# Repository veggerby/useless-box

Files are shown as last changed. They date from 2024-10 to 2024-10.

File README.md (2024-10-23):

# Useless Box

The non-attributed and non-adapted work in this repository is licensed under the [MIT LIcense](https://opensource.org/license/mit).

All files in [adjusted folder](./resources/adjusted/) are apapted work from [@balassy](https://www.thingiverse.com/thing:3856965) 3D models on Thingiverse and are licensed under [CC BY-NC-SA 4.0](https://creativecommons.org/licenses/by-nc-sa/4.0/).

## Attribution

This concept and 3D model for the enclosure, mechanical and eletronic design is based on [useless-box](https://github.com/balassy/useless-box/) and [Smart Useless Box with ESP8266 and Gesture Sensor](https://www.thingiverse.com/thing:3856965).

All source code has been created from scratch.

3D Sketches available on [Thingiverse](https://www.thingiverse.com/thing:3856965), with [local copy](./resources/Smart%20Useless%20Box%20with%20ESP8266%20and%20Gesture%20Sensor%20-%203856965.zip) and extracted [here](./resources/originals/3d-print/). These files are licensed under [CC BY-NC-SA 4.0](https://creativecommons.org/licenses/by-nc-sa/4.0/) attributed to [György Balássy](https://www.thingiverse.com/balassy/designs).

The included [Fritzing schematics](./resources/originals/Useless-Box-Shield-v1.fzz) are directly from the [GitHub repository](https://github.com/balassy/useless-box/blob/master/wiring/Useless-Box-Shield-v1.fzz) and licesed under [MIT LIcense](https://opensource.org/license/mit) attributed to György Balássy ([@balassy](https://github.com/balassy)).

## Firnware

Using [ESP32-C3 Super Mini](https://ardustore.dk/produkt/esp32-c3-super-mini-wifi-4mb-ble5-udviklingsboard)

[Datasheet](./resources/ESP32C3%20Datasheet.PDF) from [ardustore.dk](https://ardustore.dk/error/ESP32C3%20Datasheet.PDF)

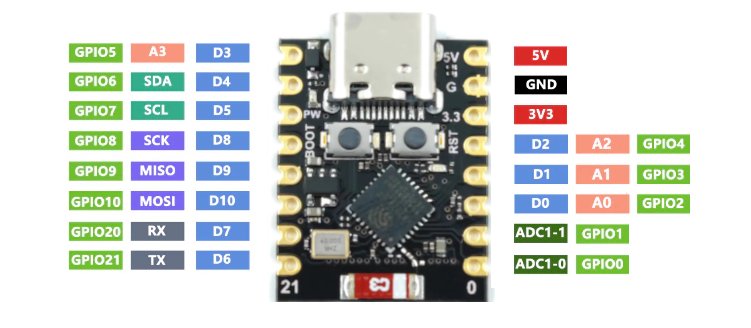
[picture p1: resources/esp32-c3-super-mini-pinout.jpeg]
ESP32-C3 Super Mini
Pinout  from [arduinio.cc](https://forum.arduino.cc/t/esp32-c3-supermini-pinout/1189850)

See [ESP32-C3 Super Mini](https://www.sudo.is/docs/esphome/boards/esp32c3supermini/) on sudo.is.

[Generic ESP32-C3 firmware](https://micropython.org/download/ESP32_GENERIC_C3/).

Included parts for the Fritzing schematics:

* [ESP32-C3 Super Mini](./resources/esp32-c3-super-mini-tht.fzpz) (from [Fritzing Forum](https://forum.fritzing.org/t/need-esp32-c3-super-mini-board-model/20561) - [direct link](https://forum.fritzing.org/uploads/short-url/oE2T2GupmkPLZawp5EHPnzf3vFM.fzpz))
* [SG90](./resources/Tower%20Pro%20SG90%20servo.fzpz) which is compatible with the MG90S used in this design (from [SolderedElectronics/e-radionica.com-Fritzing-Library-parts-](https://github.com/SolderedElectronics/e-radionica.com-Fritzing-Library-parts-/tree/master) GitHub repo - [direct link](https://github.com/SolderedElectronics/e-radionica.com-Fritzing-Library-parts-/blob/master/Tower%20Pro%20SG90%20servo.fzpz))
* [APDS-9960](./resources/12787_sfe_apds_9960_rgb_and_gesture_sensor.fzpz) (from [sparkfun/Fritzing_Parts](https://github.com/sparkfun/Fritzing_Parts/tree/main/products) GitHub repo - [direct link](https://github.com/sparkfun/Fritzing_Parts/blob/main/products/12787_sfe_apds_9960_rgb_and_gesture_sensor.fzpz))
* [2 Pin Toggle Switch](./resources/Toggle%20Switch%20spst.fzpz) (from [Fritzing Forum](https://forum.fritzing.org/t/special-type-of-spst-part/6125) - [direct link](https://forum.fritzing.org/uploads/default/original/2X/1/1c25cedde9474dec93b1165daffaadfd2b2697d7.fzpz))

### Flash

```sh
brew install esptool
```

or

```sh
pip install esptool
```

Flash ESP32:

```sh
esptool.py --chip esp32c3 --port /dev/cu.usbmodem1452201 erase_flash
esptool.py --chip esp32c3 --port /dev/cu.usbmodem1452201 --baud 460800 write_flash -z 0x0 ./firmware/ESP32_GENERIC_C3-20240602-v1.23.0.bin
```

## Components

* 1 mini breadboard
* 1 x [ESP32-C3 Super Mini](https://ardustore.dk/produkt/esp32-c3-super-mini-wifi-4mb-ble5-udviklingsboard)
* 2 x [MG90S](https://www.amazon.de/dp/B095YVLLFQ) this is compatible with the original SG90, but is more robust (metal gears) and quieter
* 1 x [APDS-9960](https://www.amazon.de/dp/B01HV41XJO) ([library](https://github.com/liske/python-apds9960))
* 1 x [2 Pin Mini On/Off Toggle Switch](https://www.amazon.de/dp/B07MS8X99G)
* 1 x 1 kΩ resistor (color code Brown-Black-Red-Gold for reference)
* Various M2 and M3 screws, nuts and washers

## 3DPrinted Box

The original files from [balassy](https://www.thingiverse.com/thing:3856965) has been adjusted to accomodate the slightly larger controller on a mini breadboard (with extended). Additionally the micro USB port has been adjusted size and position for the USB-C port on the used ESP-C3 Super Mini.

Additionally mounts have been added to the box bottom, to allow for better mounting of the servo for the lid on the box-base, using 2 M2 screws.

## Useless-Box Behavior Overview

This version of the useless-box has a controller which manages the behavior/response of the useless-box to stimuli/input. The implemented behaviors are:

### 1. Initial Setup and Idle State

* **When the program starts**, the controller initializes the box components, including the switch arm, lid arm, proximity sensor, toggle switch, and LED.
* The system enters the **IDLE** state initially, waiting for any user interaction (such as the proximity of a hand or the toggle switch being activated).

### 2. Monitoring and Responding to Proximity and Switch State

* The `update()` method continuously monitors the proximity sensor and the state of the toggle switch.
* The box reacts based on proximity levels (`VERY_CLOSE`, `CLOSE`, or `FAR`) and the toggle switch state (`On` or `Off`). Here's how each condition is handled:

### 3. Switch State Changes

* **If the toggle switch is turned on** (`current_switch` becomes `True`):
  * The system enters the `SWITCH_OFF` state.
  * The LED is turned **on** to signal the activation.
  * A **random delay** (shorter or longer, with more frequent short delays) is introduced before switching off the toggle.
  * The `_handle_switch_toggle()` method is called, which:
    * Opens the lid.
    * Attempts to switch off the toggle. If it fails, it retries up to three times.
    * Retracts the switch arm and closes the lid afterward.
  * The LED is turned **off** again, and the state resets to **IDLE**.

### 4. Proximity: Very Close Interaction

* **If a hand is detected very close** (`ProximityState.VERY_CLOSE`) and the box is in the `IDLE` state:
  * There is a **5% chance** of the box playing a **peek-a-boo** animation:
    * The lid opens slightly and then closes.
  * There is also a **20% chance** of the box threatening to turn off the toggle:
    * The switch arm moves to a halfway position as if threatening, then retracts.
  * If neither occurs, the box simply acknowledges the hand's presence but does nothing more.

* **If the lid is already open** when the hand is very close:
  * The box ensures the lid stays closed to prevent any tampering.
  * Occasionally, it might perform a **peek-a-boo** with a **1% probability**.
  * The LED blinks slowly when the hand is very close.

### 5. Proximity: Close Interaction

* **If a hand is detected close** (`ProximityState.CLOSE`) and the box is in the `IDLE` state:
  * There is a **30% chance** the box will perform a **fake-out**:
    * The lid opens slightly and quickly closes.
  * Otherwise, it enters the `TEASING` state and performs a teasing animation:
    * The lid opens to a random angle (50% to 100%), pauses, and then closes.

### 6. Proximity: Far Interaction

* **If the hand moves away** (`ProximityState.FAR`) and the box is not in the `IDLE` state:
  * The box returns to the **IDLE** state.
  * The LED is turned **off**.
  * The lid is closed if it is open, and the switch arm is retracted.

### 7. Inactivity Timeout

* The box monitors the duration since the last interaction. If the time exceeds the set `inactivity_timeout` (5 seconds in this case):
  * If the lid is open (`LID_OPEN` state), the box closes the lid and retracts the switch arm to its default position.

### 8. Panic Mode

* **If the user toggles the switch repeatedly** (three times within three seconds):
  * The box enters **panic mode**, where it:
    * Rapidly opens and closes the lid while blinking the LED for five cycles.
  * The state returns to **IDLE** after the panic mode completes.

### 9. LED Behavior Based on Proximity

* The LED behavior is tied to proximity:
  * **Very Close**: LED blinks slowly (on for half a second, off for half a second).
  * **Close**: LED blinks rapidly (on for 0.1 seconds, off for 0.1 seconds).
  * **Far**: LED remains off.

### Summary

* The `UselessBoxController` reacts dynamically based on the proximity of a hand and the toggle switch state. It performs quirky behaviors like teasing, fake-outs, peek-a-boo, threatening gestures, and panic mode to entertain and surprise users.
* The randomness introduced (through probabilities and delays) ensures that the box feels unpredictable and playful, making interactions more engaging.
* The box also incorporates safety measures, such as ensuring the lid stays closed when the hand is too close and resetting states after inactivity, providing a consistent user experience.

## Additional Works

* [Useless Box PRO with ESP8266 and Gesture Sensor](https://www.thingiverse.com/thing:5787968) remix from original

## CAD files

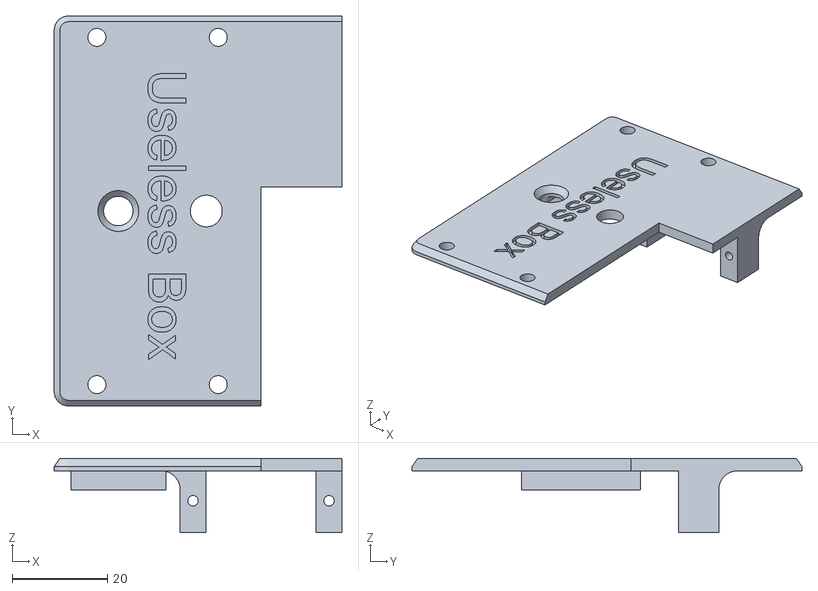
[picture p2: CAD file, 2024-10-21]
resources/adjusted/Fixed Lid.stl
60.5 x 82.0 x 15.6

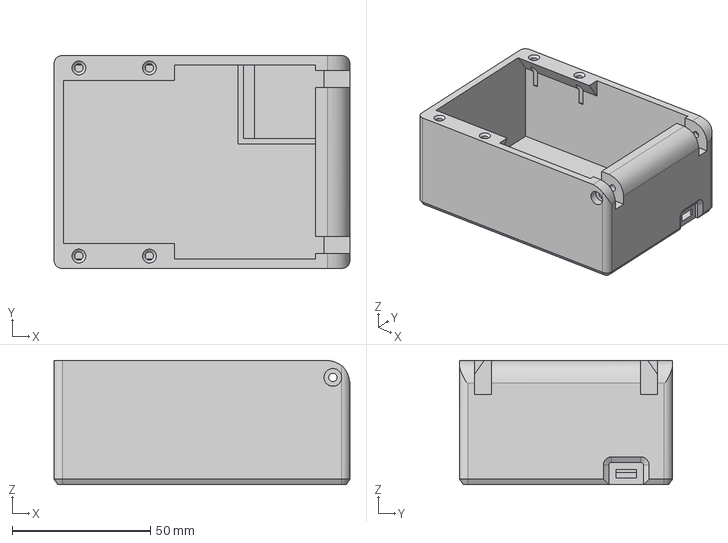
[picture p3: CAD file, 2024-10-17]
resources/originals/3d-print/files/Smart_Useless_Box_base_v1.step
107.0 x 77.0 x 45.0 mm

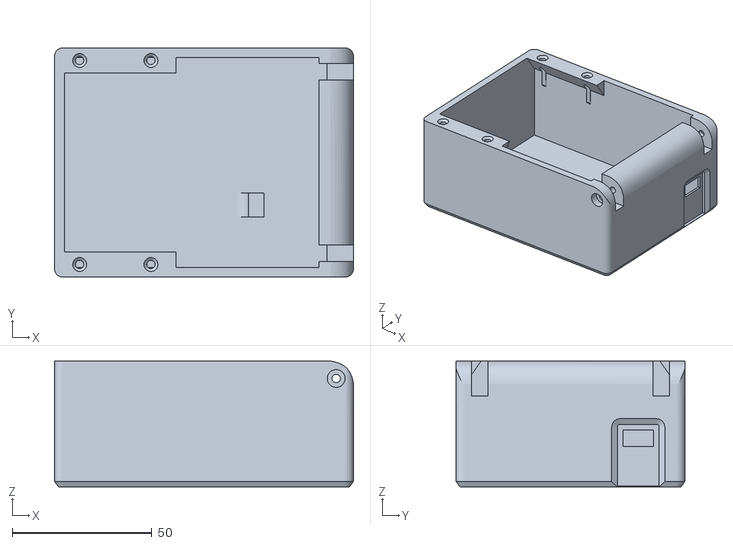
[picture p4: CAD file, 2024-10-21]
resources/adjusted/Box Base.stl
107.0 x 82.0 x 45.0

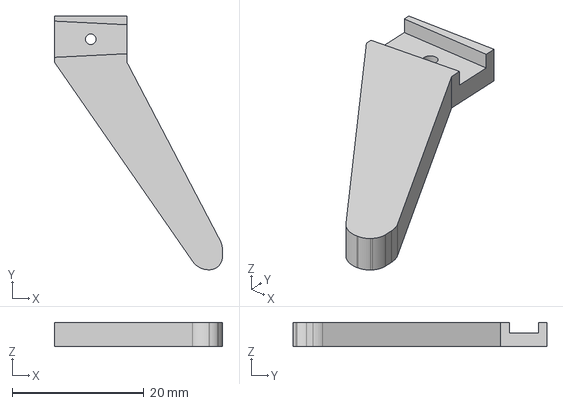
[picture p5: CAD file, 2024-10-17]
resources/originals/3d-print/files/Smart_Useless_Box_lid_arm_v1.step
25.5 x 38.5 x 3.70 mm

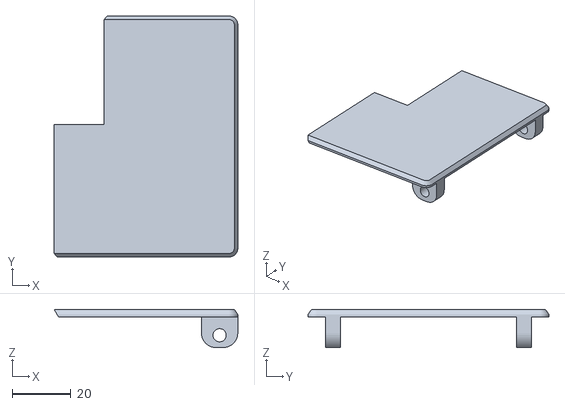
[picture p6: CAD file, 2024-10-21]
resources/adjusted/Moving Lid.stl
62.5 x 82.0 x 13.0

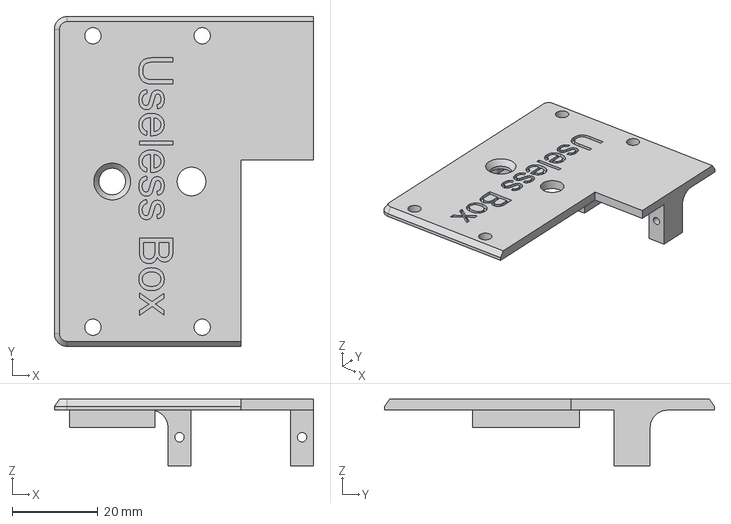
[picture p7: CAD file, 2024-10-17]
resources/originals/3d-print/files/Smart_Useless_Box_fixed_lid_v1.step
60.5 x 77.0 x 15.6 mm

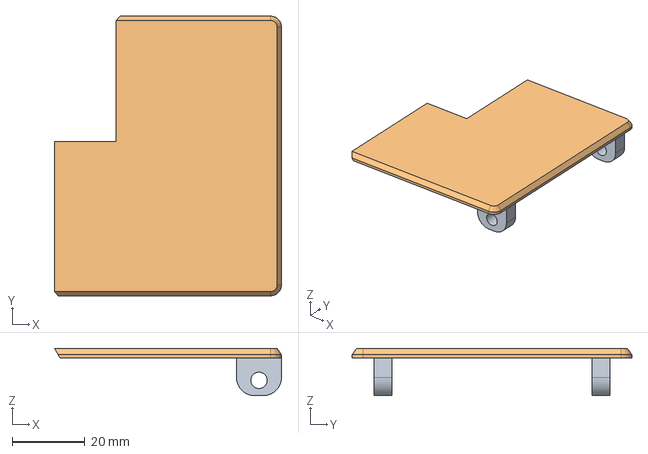
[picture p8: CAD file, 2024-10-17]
resources/originals/3d-print/files/Smart_Useless_Box_moving_lid_v1.step
62.5 x 77.0 x 13.0 mm

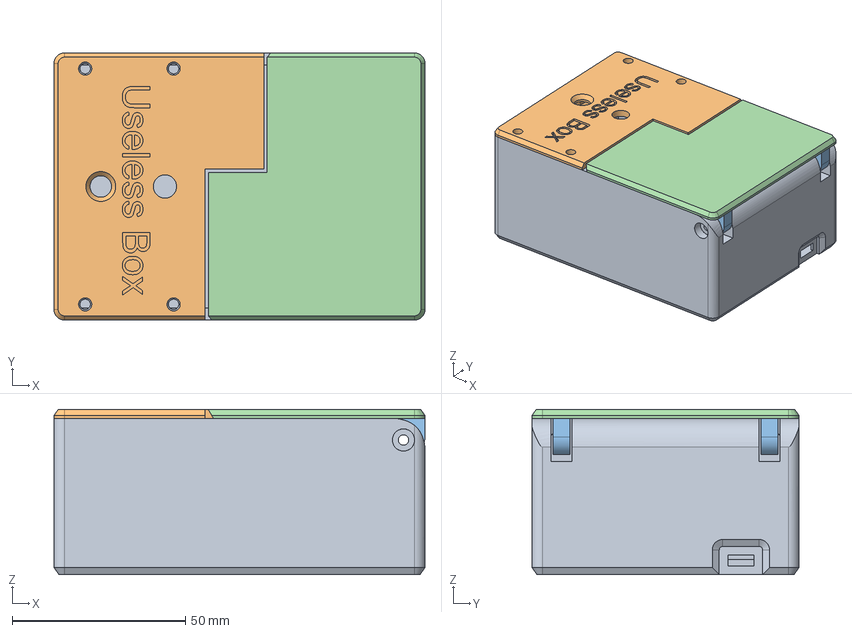
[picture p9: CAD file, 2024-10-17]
resources/originals/3d-print/files/Smart_Useless_Box_box_v1.step
107.0 x 77.0 x 47.6 mm
Box Base
Fixed Lid
Moving Lid

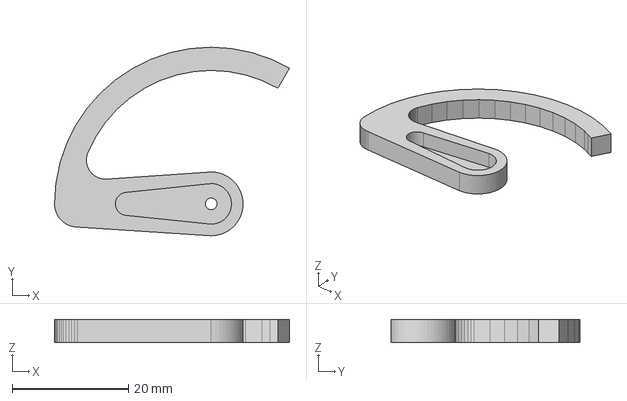
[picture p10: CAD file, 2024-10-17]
resources/originals/3d-print/files/Smart_Useless_box_switch_arm_v1.step
40.5 x 32.5 x 4.00 mm

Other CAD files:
resources/adjusted/Smart_Useless_Box_box_v2.f3d
resources/originals/3d-print/files/Smart_Useless_Box_base_v1.stl
resources/originals/3d-print/files/Smart_Useless_Box_box_v1.f3d
resources/originals/3d-print/files/Smart_Useless_Box_fixed_lid_v1.stl
resources/originals/3d-print/files/Smart_Useless_Box_lid_arm_v1.f3d
resources/originals/3d-print/files/Smart_Useless_Box_lid_arm_v1.stl
resources/originals/3d-print/files/Smart_Useless_Box_moving_lid_v1.stl
resources/originals/3d-print/files/Smart_Useless_box_switch_arm_v1.f3d
resources/originals/3d-print/files/Smart_Useless_box_switch_arm_v1.stl

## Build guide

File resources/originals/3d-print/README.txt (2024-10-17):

Smart Useless Box with ESP8266 and Gesture Sensor by balassy on Thingiverse: https://www.thingiverse.com/thing:3856965

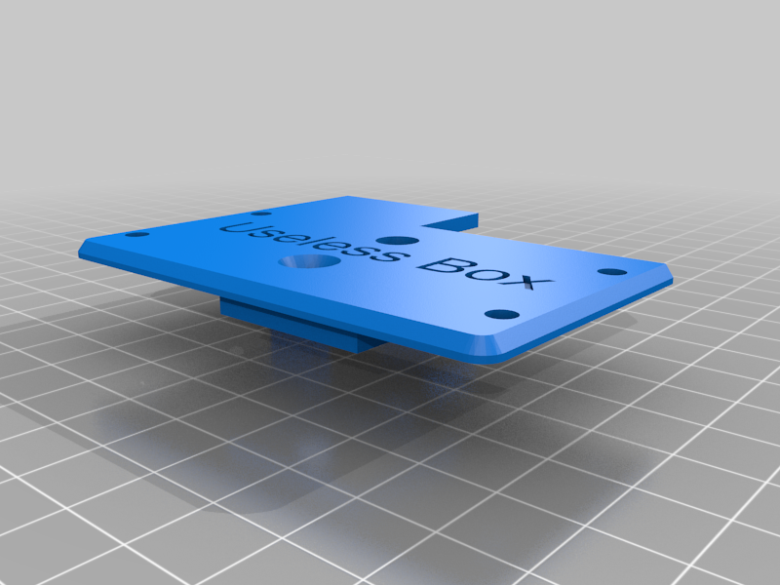
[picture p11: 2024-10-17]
resources/originals/3d-print/images/Smart_Useless_Box_fixed_lid_v1.png

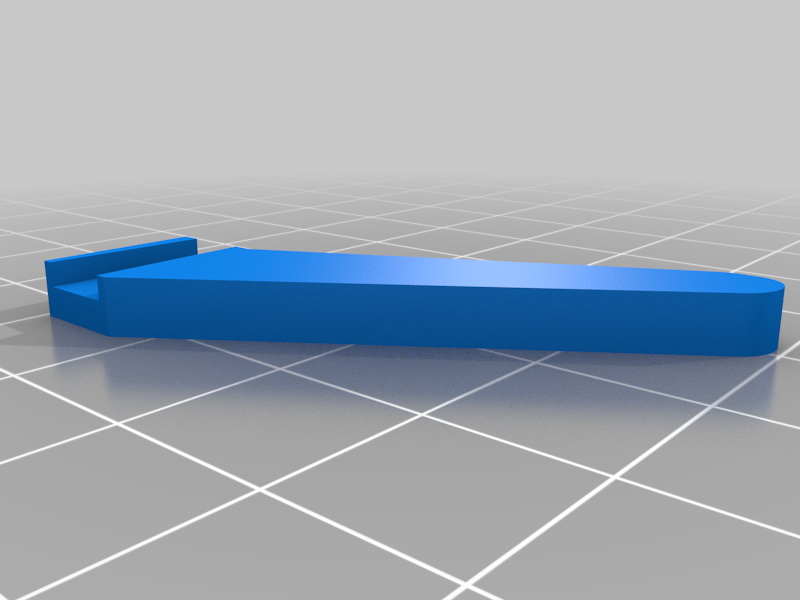
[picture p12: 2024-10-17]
resources/originals/3d-print/images/Smart_Useless_Box_lid_arm_v1.png

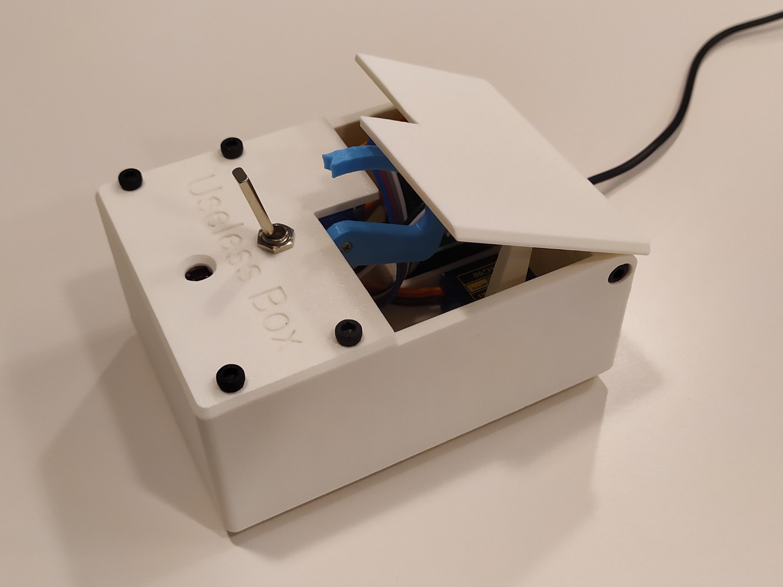
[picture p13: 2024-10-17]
resources/originals/3d-print/images/Smart_useless_box_1.jpg

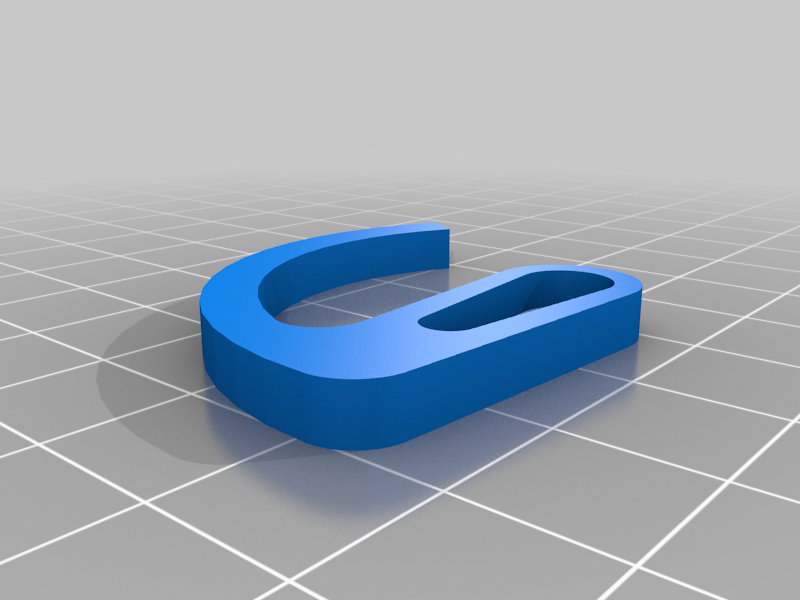
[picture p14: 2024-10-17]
resources/originals/3d-print/images/Smart_Useless_box_switch_arm_v1.png

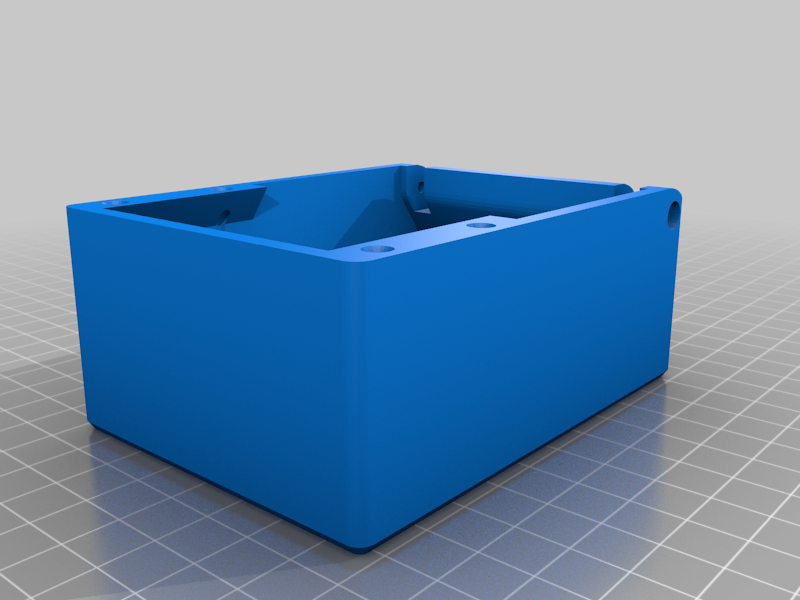
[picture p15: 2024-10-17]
resources/originals/3d-print/images/Smart_Useless_Box_base_v1.png

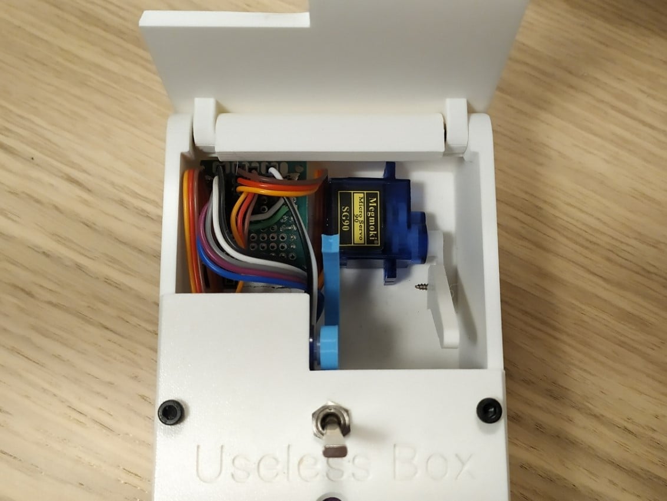
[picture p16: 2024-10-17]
resources/originals/3d-print/images/IMG_20210421_183354.jpg

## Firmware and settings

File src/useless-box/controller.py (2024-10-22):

import random
import time
from proximity import ProximityState
from led import LED
from useless_box import UselessBox

class UselessBoxController:
    PEEKABOO_PROBABILITY = 0.05  # Probability for peek-a-boo (5%)
    THREATEN_PROBABILITY = 0.2   # Probability for threatening movement (20%)
    PEEKABOO_RARE_PROBABILITY = 0.01  # Probability when hand is very close (1%)

    IDLE = 0
    LID_OPEN = 1
    TEASING = 2
    SWITCH_OFF = 3

    MAX_SWITCH_ON_TIME_SECS = 10

    def __init__(self, switch_pin, lid_pin, sda_pin, scl_pin, toggle_pin, led_pin, inactivity_timeout=5):
        """
        Initializes the UselessBoxController with the necessary components.
        :param switch_pin: GPIO pin connected to the switch arm servo.
        :param lid_pin: GPIO pin connected to the lid arm servo.
        :param sda_pin: GPIO pin used for the I2C data line (SDA).
        :param scl_pin: GPIO pin used for the I2C clock line (SCL).
        :param toggle_pin: GPIO pin connected to the toggle switch.
        :param led_pin: GPIO pin connected to the LED.
        :param inactivity_timeout: Time in seconds before the lid closes automatically if no interaction occurs.
        """
        self.box = UselessBox(switch_pin, lid_pin, sda_pin, scl_pin, toggle_pin)
        self.led = LED(led_pin)  # Initialize the onboard LED
        self.state = UselessBoxController.IDLE
        self.last_state = None
        self.last_proximity = None
        self.last_switch_state = None
        self.inactivity_timeout = inactivity_timeout  # Inactivity timeout in seconds
        self.last_interaction_time = time.time()  # Track the last time an interaction occurred
        self.switch_off_count = 0
        self.last_off_time = time.time()
        self.last_on_time = None

    def run(self):
        """
        Main method to run the interactive sequences based on user input.
        """
        while True:
            self.update()

    def update(self):
        """
        Updates the box's behavior based on the state of the toggle switch and proximity sensor.
        """
        current_switch = self.box.get_switch_state()
        proximity = self.box.get_proximity()

        # Output proximity state only if it has changed
        if proximity != self.last_proximity:
            print(f"Proximity state: {proximity}")

        # Output switch state only if it has changed
        if current_switch != self.last_switch_state:
            print(f"Switch state: {'On' if current_switch else 'Off'}")

            if current_switch:
                self.last_on_time = time.time()

        if self.state != self.last_state:
            print(f"State: {self.state}")

        self.last_state = self.state

        # Check for interactions and update the state
        if current_switch and not self.last_switch_state:
            self.state = UselessBoxController.SWITCH_OFF
            self.led.on()  # Turn on the LED when the switch is turned on
            self._random_delay()  # Introduce a random delay before switching off
            self._handle_switch_off()
            self._reset_inactivity_timer()

        elif proximity == ProximityState.VERY_CLOSE and self.state == UselessBoxController.IDLE:
            # Occasionally play peek-a-boo (5% chance)
            if random.random() < UselessBoxController.PEEKABOO_PROBABILITY:
                self.state = UselessBoxController.LID_OPEN
                self._handle_peekaboo()
                self._reset_inactivity_timer()
            # Occasionally move the switch arm to a threatening position (20% chance)
            elif random.random() < UselessBoxController.THREATEN_PROBABILITY:
                print("Threatening to switch off!")
                self._handle_threaten()
                self._reset_inactivity_timer()
            else:
                print("Hand detected very close, but not playing peek-a-boo or threatening this time.")

        elif proximity == ProximityState.CLOSE and self.state == UselessBoxController.IDLE:
            if random.random() < 0.3:  # 30% chance of doing a fake-out
                self._handle_fakeout()
            else:
                self.state = UselessBoxController.TEASING
                self._handle_tease()
            self._reset_inactivity_timer()

        elif proximity == ProximityState.FAR and self.state != UselessBoxController.IDLE:
            self.state = UselessBoxController.IDLE
            self.led.off()  # Turn off the LED when returning to idle
            self._handle_close_lid()
            self._reset_inactivity_timer()

        # If proximity is very close, ensure the lid stays closed and occasionally blink the LED
        elif proximity == ProximityState.VERY_CLOSE:
            if self.state != UselessBoxController.IDLE:
                print("Hand too close, keeping the lid closed.")
                self._handle_close_lid()
                self.led.off()
            # Occasionally do a peek-a-boo, even when proximity is very close, and blink the LED
            elif random.random() < UselessBoxController.PEEKABOO_RARE_PROBABILITY:
                self.led.toggle()  # Blink the LED occasionally
                self.state = UselessBoxController.LID_OPEN
                self._handle_peekaboo()
                self._reset_inactivity_timer()

        # If the switch is turned on for a long time, switch off automatically
        if current_switch and self.state == UselessBoxController.IDLE and self.last_on_time is not None and time.time() - self.last_on_time > self.MAX_SWITCH_ON_TIME_SECS:
            print("Switch has been on for a while. Turning it off automatically.")
            self._handle_switch_off()

        # Close the lid if it is open and there has been no interaction for the specified inactivity period
        if time.time() - self.last_interaction_time > self.inactivity_timeout:
            if self.state == UselessBoxController.LID_OPEN:
                print("No interaction detected for a while. Closing the lid.")
                self._handle_close_lid()

        self.update_led_based_on_proximity(proximity)  # Update LED pattern based on proximity

        self.last_switch_state = current_switch
        self.last_proximity = proximity
        time.sleep(0.2)  # Small delay for responsiveness

    def _random_delay(self):
        """
        Introduces a random delay before taking action after the switch is turned on.
        Short delays are more common, with longer delays being rarer.
        """
        random_value = random.uniform(0, 1)
        if random_value < 0.3:
            chosen_delay = 0.5
        elif random_value < 0.6:
            chosen_delay = 1.0
        elif random_value < 0.8:
            chosen_delay = 1.5
        elif random_value < 0.9:
            chosen_delay = 2.0
        elif random_value < 0.95:
            chosen_delay = 3.0
        else:
            chosen_delay = 5.0

        print(f"Introducing a delay of {chosen_delay} seconds.")
        time.sleep(chosen_delay)

    def update_led_based_on_proximity(self, proximity):
        if proximity == ProximityState.VERY_CLOSE:
            self.led.on() if time.time() % 1 < 0.5 else self.led.off()  # Blink slowly
        elif proximity == ProximityState.CLOSE:
            self.led.on() if time.time() % 0.2 < 0.1 else self.led.off()  # Blink quickly
        else:
            self.led.off()

    def _handle_switch_off(self):
        """
        Handles the switch toggle interaction.
        Ensures the switch is actually turned off by the arm.
        """
        current_time = time.time()
        if current_time - self.last_off_time < 3:
            self.switch_off_count += 1
        else:
            self.switch_off_count = 1
        self.last_off_time = current_time

        if self.switch_off_count >= 3:
            self._handle_panic_mode()
            self.switch_off_count = 0
            return

        print("Switch turned on, attempting to turn it off.")
        self.box.open_lid(100, 500)
        time.sleep(0.5)  # Small delay to give a visual effect of the lid opening

        # Attempt to turn off the switch
        for attempt in range(3):
            print(f"Attempt {attempt + 1} to switch off.")
            self.box.switch_arm.extend(100, 500)  # Move the switch arm fully to turn the switch off
            time.sleep(0.5)  # Hold position to ensure it engages
            self.box.switch_arm.retract(100, 500)  # Retract the switch arm after switching off

            # Recheck the switch state after attempting to turn it off
            if not self.box.get_switch_state():
                print("Switch successfully turned off.")
                break
            else:
                print("Switch still on, retrying...")

        self.box.close_lid(100, 500)  # Close the lid fully
        self.led.off()  # Turn off the LED after handling the toggle
        self.state = UselessBoxController.IDLE

    def _handle_peekaboo(self):
        """
        Handles the peek-a-boo interaction.
        """
        self.box.play_peekaboo()
        self.state = UselessBoxController.IDLE

    def _handle_tease(self):
        """
        Handles the teasing interaction with a random lid angle.
        """
        random_angle = random.randint(50, 100)  # Randomly choose an angle between 50% and 100%
        print(f"Teasing with lid opening to {random_angle}%")
        self.box.open_lid(random_angle, 500)
        time.sleep(0.5)
        self.box.close_lid(0, 500)
        self.state = UselessBoxController.IDLE
    def _handle_threaten(self):
        """
        Handles the threatening movement of the switch arm.
        Ensures the lid is open before threatening.
        """
        if not self.box.lid_arm.is_open():  # Check if the lid is already open
            self.box.open_lid(100, 500)  # Open the lid fully if it's not

        self.box.switch_arm.extend(50, 300)  # Move arm halfway as if threatening to switch
        time.sleep(0.5)
        self.box.switch_arm.retract(50, 300)
        self.state = UselessBoxController.LID_OPEN  # Set state to LID_OPEN

    def _handle_close_lid(self):
        """
        Handles closing the lid when no hand is detected close or after inactivity.
        Ensures the switch arm is retracted before closing the lid.
        """
        print("Retracting switch arm and closing lid.")
        self.box.switch_arm.retract(100, 300)  # Ensure the switch arm is fully retracted
        self.box.close_lid(100, 500)  # Fully close the lid (100%)
        self.state = UselessBoxController.IDLE

    def _handle_fakeout(self):
        """
        Handles a fake-out interaction where the lid opens slightly and then closes quickly.
        """
        print("Fake-out! Opening lid slightly...")
        self.box.open_lid(30, 300)  # Open lid to 30% quickly
        time.sleep(0.3)
        print("Closing quickly!")
        self.box.close_lid(0, 200)  # Close lid quickly
        self.state = UselessBoxController.IDLE

    def _handle_panic_mode(self):
        """
        Handles a panic mode where the box rapidly opens and closes the lid while blinking the LED.
        """
        print("Entering panic mode!")
        for _ in range(5):
            self.box.open_lid(100, 200)
            self.led.toggle()
            time.sleep(0.2)
            self.box.close_lid(0, 200)
            self.led.toggle()
            time.sleep(0.2)
        self.state = UselessBoxController.IDLE

    def _reset_inactivity_timer(self):
        """
        Resets the inactivity timer to the current time.
        """
        self.last_interaction_time = time.time()

if __name__ == "__main__":
    controller = UselessBoxController(
        switch_pin=0,
        lid_pin=2,
        sda_pin=6,
        scl_pin=7,
        toggle_pin=21,
        led_pin=8,
        inactivity_timeout=5  # Set to 5 seconds, but you can adjust as needed
    )
    controller.run()

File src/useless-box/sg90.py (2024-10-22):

from machine import Pin, PWM
from time import sleep_ms

class SG90Servo:
    PWM_FREQ = 50  # 50 Hz (20 ms period)
    MIN_DUTY = 26  # 5% duty cycle
    MAX_DUTY = 123  # 10% duty cycle

    def __init__(self, pin, default_angle=0):
        """
        Initializes the SG90 servo.
        :param pin: The GPIO pin connected to the servo.
        :param default_angle: The default starting angle of the servo (default is 0 degrees).
        """
        self.servo = PWM(Pin(pin, mode=Pin.OUT))
        self.servo.freq(self.PWM_FREQ)  # Set the frequency to 50 Hz (20 ms period)
        self.default_angle = default_angle  # Set the default angle
        self.current_angle = self.default_angle  # Initialize current angle
        self.move_to_angle(self.default_angle)  # Move to the default angle on initialization

    def angle_to_duty(self, angle):
        """
        Converts the angle (0-180 degrees) to the corresponding duty cycle.
        :param angle: The angle to move the servo to (0 to 180 degrees).
        :return: The duty cycle percentage corresponding to the angle.
        """
        # Interpolate between these values based on the angle
        if angle <= 0:
            duty = self.MIN_DUTY
        elif angle >= 180:
            duty = self.MAX_DUTY
        else:
            duty = self.MIN_DUTY + (angle / 180) * (self.MAX_DUTY - self.MIN_DUTY)
        return int(duty)

    def move_to_angle(self, angle, force = False):
        """
        Moves the servo to the specified angle.
        :param angle: The angle to move the servo to (0 to 180 degrees).
        """
        # round to 2 decimal places, so we have a chance of reducing unwanted servo adjustments
        angle = round(angle, 2)

        # do we need to move?
        if not force and angle == self.current_angle:
            return

        duty_value = self.angle_to_duty(angle)
        self.servo.duty(duty_value)
        self.current_angle = angle  # Update the current angle
        sleep_ms(250)  # Wait for the servo to move

    def move_smoothly(self, target_angle, duration_full_range=1000, steps=50):
        """
        Moves the servo smoothly from the current angle to the target angle over a specified duration.
        The duration is relative to a full 0-180 degree movement.

        :param target_angle: The target angle to move the servo to (0 to 180 degrees).
        :param duration_full_range: The duration in milliseconds for a full 0-180 degree movement.
        :param steps: Number of steps for smooth movement.
        """
        start_angle = self.current_angle
        angle_difference = abs(target_angle - start_angle)

        # Calculate the duration relative to the angle difference
        duration = (angle_difference / 180) * duration_full_range

        start_duty = self.angle_to_duty(start_angle)
        end_duty = self.angle_to_duty(target_angle)

        delay = int(duration / steps)
        step_size = (end_duty - start_duty) / steps

        for step in range(steps + 1):
            duty_value = int(start_duty + step * step_size)
            self.servo.duty(duty_value)
            sleep_ms(delay)

        self.current_angle = target_angle  # Update the current angle to the target angle

    def reset(self):
        """
        Resets the servo to the default starting angle (default is 0 degrees) instantly.
        """
        print(f"Resetting servo to {self.default_angle} degrees.")
        self.move_to_angle(self.default_angle, force=True)  # Move instantly to the default angle

# Example usage
if __name__ == "__main__":
#     servo1 = SG90Servo(0, default_angle=40)
#     sleep_ms(1000)
#     servo1.move_to_angle(173)
#     sleep_ms(1000)
#     servo1.reset()

    servo2 = SG90Servo(2, default_angle=90)
    servo2.reset()
    sleep_ms(1000)
    servo2.move_to_angle(30)
    sleep_ms(1000)
    servo2.reset()
   

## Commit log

2024-10-17 initial commit basics
    [Smart_Useless_Box_base_v1.step, Smart_Useless_Box_base_v1.stl, Smart_Useless_Box_box_v1.f3d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]
2024-10-21 initial verxion - not doing proper behavior but controls are in place
    [Box Base.stl, Fixed Lid.stl, Moving Lid.stl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]
2024-10-22 decent behavior
    [Smart_Useless_Box_box_v2.f3d]
2024-10-22 fix switch state
2024-10-22 auto switch off after timeout
